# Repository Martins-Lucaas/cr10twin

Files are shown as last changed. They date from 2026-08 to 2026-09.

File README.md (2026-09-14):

<div align="center">

# cr10twin
### Digital Twin · CR10 + COVVI Hand · Biomedical Manufacturing Cell








</div>

<p align="center">
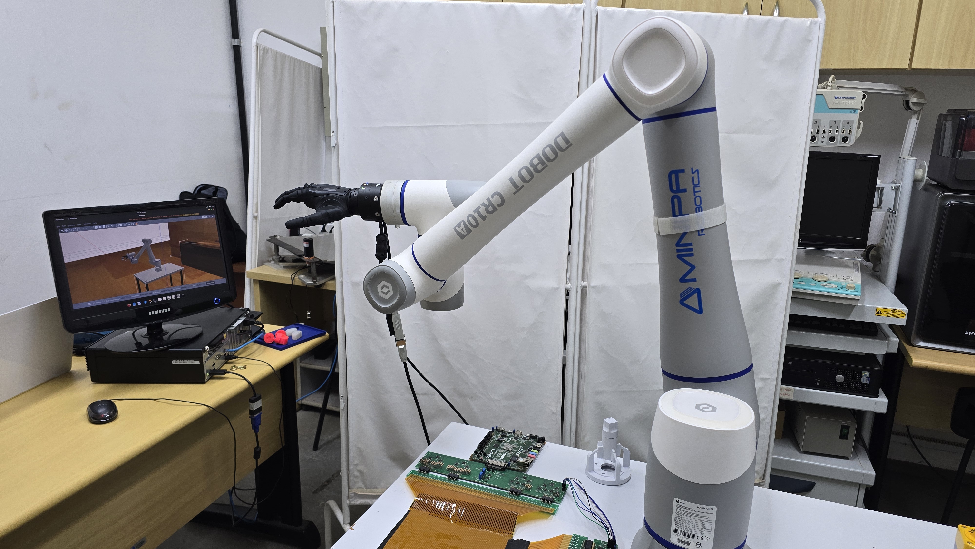
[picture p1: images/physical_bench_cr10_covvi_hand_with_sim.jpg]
Physical bench: Dobot CR10A arm with the COVVI hand mounted on the flange, and the Gazebo digital twin mirrored on the monitor at the left
  
</p>
<p align="center"><em>The physical bench — <strong>Dobot CR10A</strong> with the <strong>COVVI Hand</strong> on the flange — next to the Gazebo digital twin running the same pose.</em></p>

Digital twin of the **Dobot CR10** industrial arm coupled to the **COVVI Hand** bionic prosthetic hand, running on **ROS 2 Humble / Gazebo Classic 11**. The system identifies pharmaceutical objects on a conveyor, classifies them by the grasp type they require and drops them into the correct bins — with a direct channel to the physical COVVI hand over the ECI Ethernet protocol.

Part of an **undergraduate thesis (TCC) in Biomedical Engineering** — a virtual platform to support the training of users of multi-DOF prosthetic hands. The same hardware (CR10 + COVVI) is reused in a second **tactile palpation** cell, which reproduces the protocol of Gupta et al. 2021 with force control and Cartesian sliding.

> 🎬 **Project overview video:** [`images/tcc_video_visao_geral.mp4`](images/tcc_video_visao_geral.mp4) *(11 MB — GitHub plays it in the file viewer)*

---

## The sim ↔ real bridge

<p align="center">
  Diagram of the bidirectional Sim-to-Real and Real-to-Sim bridge between the digital twin and the CR10 + COVVI hardware
</p>
<p align="center"><em>One direction at a time, selected by mode: <strong>Sim-to-Real</strong> (the twin commands, the hardware replicates — ServoJ streaming at 33 Hz, MovJ on manual jog, COVVI hand over ECI) and <strong>Real-to-Sim</strong> (the hardware commands, the twin replicates — joint feedback at 125 Hz, which enables drag teach). Diagram labels are in Portuguese.</em></p>

<p align="center">
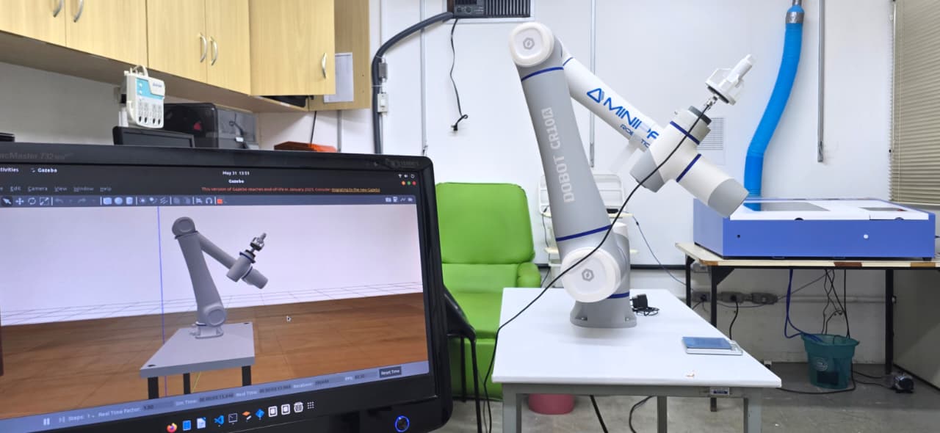
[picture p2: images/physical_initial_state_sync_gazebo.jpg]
Real CR10 next to a monitor where Gazebo shows the simulated arm in the exact same pose after startup synchronization
  
</p>
<p align="center"><em>At startup, <code>real_pose_sync</code> reads the real arm's pose and drives Gazebo to it (~3 s), so the twin is born synchronized rather than in an arbitrary URDF pose.</em></p>

---

## Hardware

| Component | Model | Specifications |
|---|---|---|
| Arm | **Dobot CR10A** | 6-DOF, 1300 mm reach, 10 kg payload, ±0.03 mm repeatability, TCP/IP V4 protocol |
| Hand | **COVVI Hand** | 5 fingers + 31 joints (6 primary + 25 mimic), ECI Ethernet interface |
| Camera | Gazebo RGB | 848×480, 70° FoV, mounted behind the conveyor |
| Load cell | 100 kg S-type cell + HX711 on a **XIAO ESP32S3** | **USB CDC only** at 115200 baud, one line per sample: `F,<seq>,<t_us>,<v_sensor>`. The WiFi/UDP path was removed on 27/07/2026 (packet loss + jitter in the HX711 front end) |
| Touch sensor | STM32 + taxel array — **4×4 or 5×5**, selected with `sensor:=4\|5` | USB-CDC at 115200 baud; Izhikevich neuromorphic model (RA/SA spikes + `I_final`). Optional UDP relay: **8081** (scalar) · **8082** (raw frame) |

<p align="center">
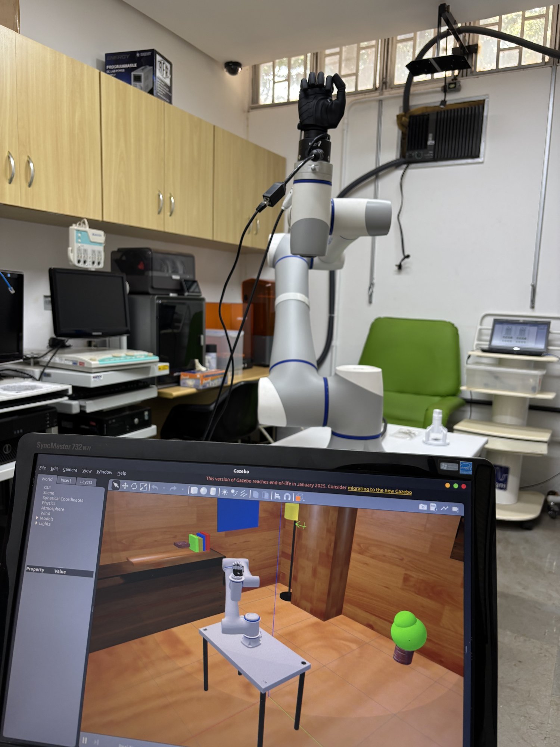
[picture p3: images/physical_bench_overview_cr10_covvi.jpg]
Full lab bench: the CR10 arm with the COVVI hand, and the Gazebo digital twin on the monitor in the foreground
  
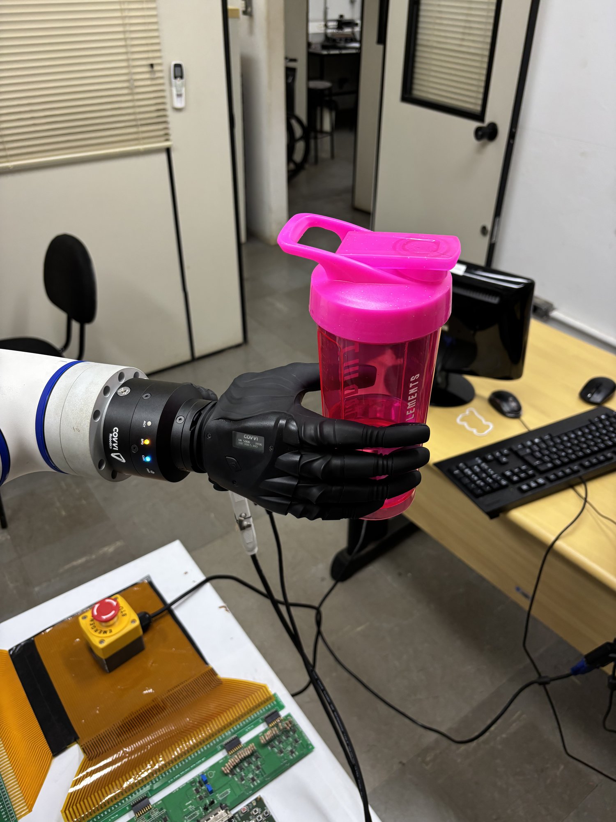
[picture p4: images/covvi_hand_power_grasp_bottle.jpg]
COVVI hand mounted on the CR10 flange holding a bottle in a power grasp
  
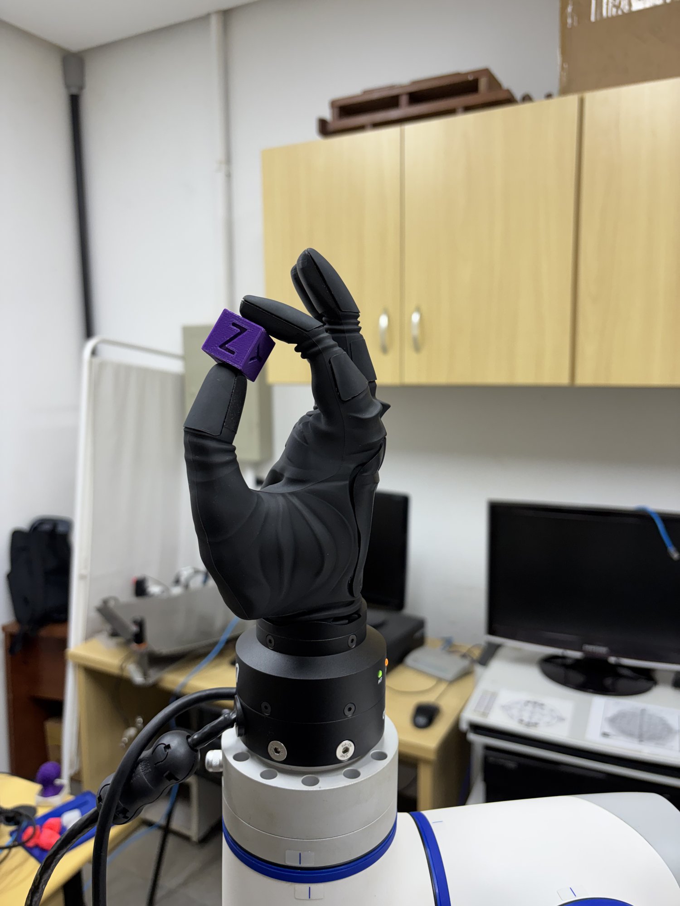
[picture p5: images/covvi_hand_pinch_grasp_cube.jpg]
COVVI hand pinching a small 3D-printed cube between thumb and index finger
  
</p>
<p align="center"><em>The real hardware in the lab: the bench with the twin on screen · a <strong>power grasp</strong> on a bottle · a <strong>pinch grasp</strong> on a 3D-printed cube.</em></p>

---

## Installation

### Option A — Docker (reproducible, one command)

```bash
git clone --recursive https://github.com/Martins-Lucaas/cr10twin.git ~/cr10twin
cd ~/cr10twin
xhost +local:docker                       # once per session, for the GUI
docker compose run --build cr10twin       # shell in a built workspace
```

The image (`Dockerfile`) pins ROS 2 Humble + every dependency and runs
`colcon build`; `docker-compose.yml` bind-mounts your checkout so you edit on the
host and re-run `colcon build` inside. Uncomment the `devices:` block for the
real load cell / touch sensor. This is the same environment CI builds on every
push.

### Option B — native

```bash
# 1. Clone WITH the eci_ros submodule (COVVI hand driver)
git clone --recursive https://github.com/Martins-Lucaas/cr10twin.git ~/cr10twin
cd ~/cr10twin
#    Already cloned without --recursive?  git submodule update --init --recursive

# 2. Dependencies
rosdep install --from-paths src --ignore-src -r -y      # apt + system deps
pip install "numpy<2" pyserial matplotlib               # numpy<2 = cv_bridge ABI
#    Optional extras (YOLO / model training / mesh regen): see "Full dependency list".

# 3. Build and source
colcon build --symlink-install
source install/setup.bash
```

`cra_description` (the CR10 URDF) is already versioned in the repository; `eci_ros`
arrives through the submodule. Nothing beyond step 1 needs to be cloned.

> **Updating the submodule later:** `git submodule update --remote src/eci_ros`
> **`symbolic link ... Is a directory` error during the build:** `rm -rf build install && colcon build --symlink-install`
> **Always run `source install/setup.bash`** in every new terminal before any `ros2 launch`/`ros2 run`.

---

## Full dependency list

> `rosdep install --from-paths src --ignore-src -r -y` now resolves the build and
> runtime dependencies — the `package.xml` files were completed (numpy, matplotlib,
> pyserial, tk, xacro, `ament_index_python`, `covvi_interfaces`, and for `hand_pack`
> also `rclpy` / `sensor_msgs` / `trajectory_msgs`). Two deliberate exceptions
> remain: **`hand_pack` is not declared** as a dependency of
> `touch_pack`/`grasp_ml_pack` (their launch files import `hand_pack.urdf_helpers`,
> but `hand_pack` already depends on both — colcon would reject the cycle), and
> the **optional** `scikit-learn` / `torch` / `ultralytics` (YOLO + model training)
> and `cadquery-ocp` (TCP mesh regen) stay `pip`-only, listed below.

### Operating system

| Dependency | Version |
|---|---|
| Ubuntu | 22.04 LTS |
| ROS 2 | Humble Hawksbill — install **`ros-humble-desktop`**, which brings `rviz2` and `rqt_joint_trajectory_controller` (both declared by `hand_pack`) |
| Gazebo | Classic 11 |
| Python | 3.10+ |

### apt packages

```bash
sudo apt update && sudo apt install -y \
  ros-humble-gazebo-ros-pkgs \
  ros-humble-ros2-control \
  ros-humble-ros2-controllers \
  ros-humble-gazebo-ros2-control \
  ros-humble-xacro \
  ros-humble-joint-state-publisher-gui \
  ros-humble-vision-msgs \
  ros-humble-cv-bridge \
  ros-humble-control-msgs \
  ros-humble-admittance-controller \
  ros-humble-kinematics-interface-kdl \
  ros-humble-force-torque-sensor-broadcaster \
  python3-tk \
  python3-pil \
  python3-pytest \
  python3-colcon-common-extensions \
  git
```

### Python

```bash
# numpy<2 is mandatory — Humble's cv_bridge is compiled against NumPy 1.x
pip install "numpy<2" opencv-python

# touch_pack — load-cell serial port and the Sensors-tab plots
pip install pyserial matplotlib

# COVVI hand driver — proprietary ECI library from COVVI Robotics
pip install covvi-eci==1.1.6

# Optional — YOLOv8 detector (only grasp_ml_pack with use_yolo:=true)
pip install ultralytics

# Optional — train the GraspQualityNet (src/grasp_ml_pack/scripts/train_grasp_model.py).
# scikit-learn drives the 'rf' backend, torch the 'nn' one. models/ ships empty,
# so anyone who wants the model has to train it.
pip install scikit-learn torch

# Optional — regenerate the palpation TCP meshes/inertias from cad/step/*.step
pip install cadquery-ocp
```

> **Optional, apt:** `python3-vtk9` enables the GPU backend of the **3D Manipulation** tab
> (the exact URDF mesh, offscreen). Without it the tab falls back to the decimated CPU
> renderer — nothing breaks.

### External dependencies — already handled by the repository

| Package | Origin | How it gets in |
|---|---|---|
| `cra_description` | extracted from [`Dobot-Arm/DOBOT_6Axis_ROS2_V4`](https://github.com/Dobot-Arm/DOBOT_6Axis_ROS2_V4) | **already versioned** under `src/cra_description` — nothing to clone |
| `covvi_interfaces` + `covvi_hand_driver` (`src/eci_ros`) | **git submodule** | cloned automatically with `git clone --recursive` (see Installation) |

> **Credits — COVVI hand driver:** `src/eci_ros` is authored by **COVVI Robotics** ([`COVVI-Robotics/eci_ros`](https://github.com/COVVI-Robotics/eci_ros)), released by them under Apache-2.0 and maintained upstream by Jordan Birdsall. It is included as a submodule pointing to a fork ([`Martins-Lucaas/eci_ros`](https://github.com/Martins-Lucaas/eci_ros)) that **fully preserves the original authorship, licence and maintainer**. The fork carries two downstream changes only: closing the ECI session on shutdown, and declaring the `rclpy` / `covvi_interfaces` runtime dependencies that the original `package.xml` omitted.

> **Note:** even in simulation-only mode, `covvi_interfaces` must be built — several nodes lazily import those types to command the real hand when it is enabled.

---

## Package guide

Each package documents how to run it in its own README.

<p align="center">
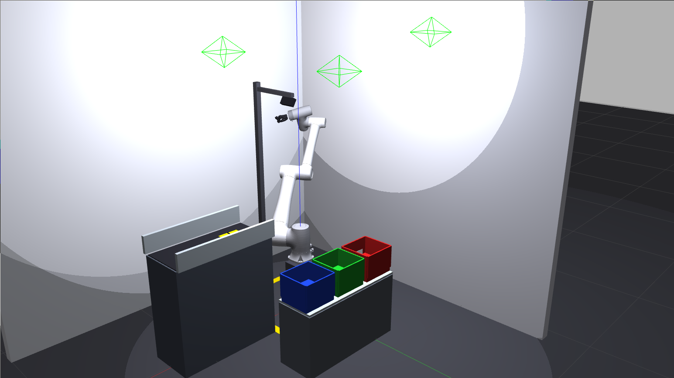
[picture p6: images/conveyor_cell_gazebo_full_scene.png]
grasp_ml_pack — the manufacturing cell in Gazebo with conveyor, arm and destination bins
  
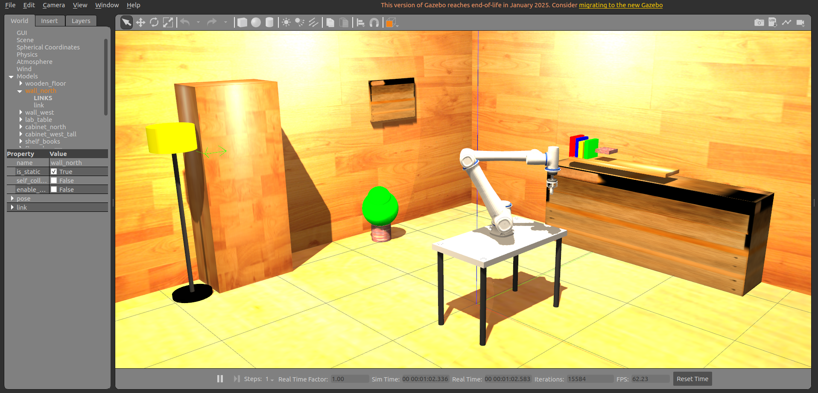
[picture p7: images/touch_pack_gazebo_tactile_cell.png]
touch_pack — the tactile palpation cell in Gazebo with the CR10 and the TouchTool tip
  
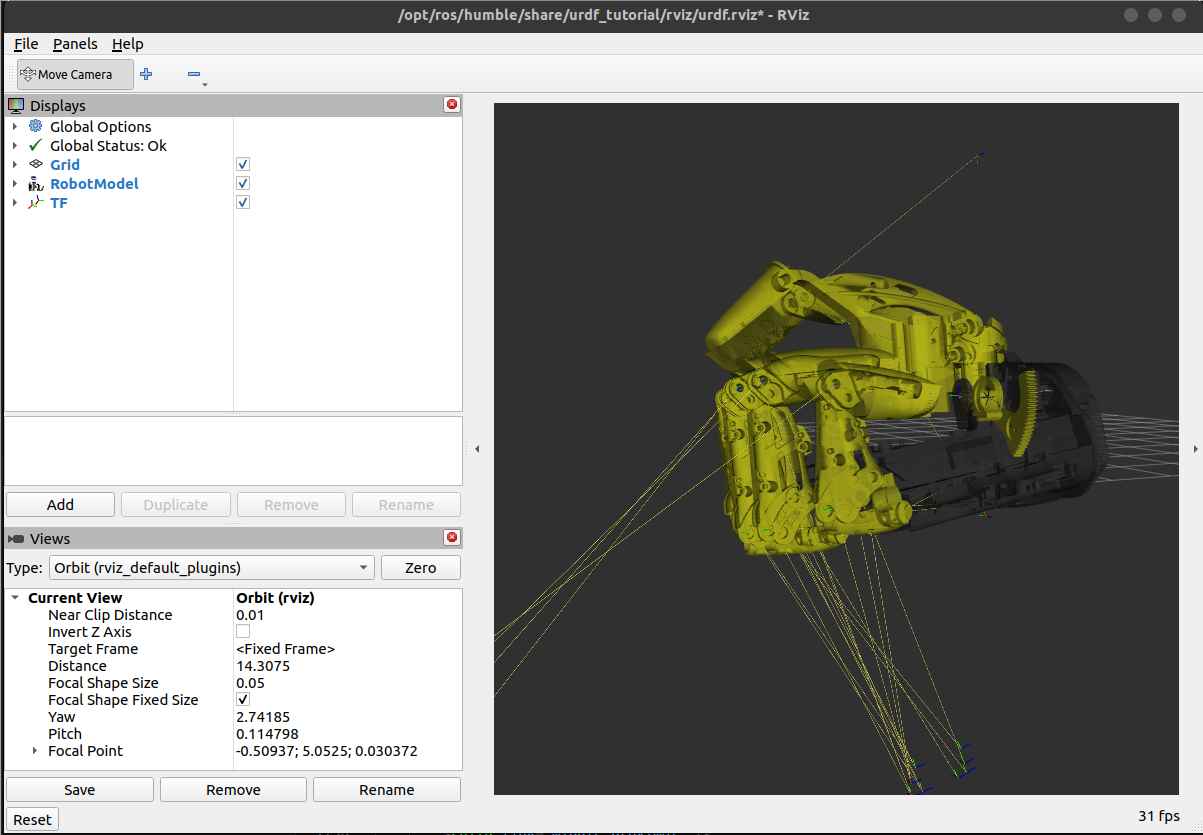
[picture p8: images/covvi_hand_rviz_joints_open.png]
hand_pack — the COVVI hand URDF in RViz with the fingers open
  
</p>
<p align="center"><em><code>grasp_ml_pack</code> — manufacturing cell · <code>touch_pack</code> — tactile palpation cell · <code>hand_pack</code> — combined CR10 + COVVI URDF.</em></p>

| Package | Main role | README |
|---|---|---|
| **`grasp_ml_pack`** | Manufacturing cell: conveyor, object detection, pick-and-place with COVVI | [→ grasp_ml_pack/README.md](src/grasp_ml_pack/README.md) |
| **`hand_pack`** | Combined CR10 + COVVI URDF, hand GUIs, launch helpers | [→ hand_pack/README.md](src/hand_pack/README.md) |
| **`touch_pack`** | Tactile palpation cell: Gupta 2021 protocol (Touch · Slide · Manual · Matrix map), GUI with 3D manipulation, logging, XIAO load cell + STM32 touch sensor (Izhikevich) | [→ touch_pack/README.md](src/touch_pack/README.md) |
| **`touch_pack_msgs`** | Message package for the palpation cell: `PalpationStart`, `PalpationStatus`, `MatrixPoint`, `SyncedTouch` | — |
| **`cra_description`** | URDF/Xacro of the Dobot CR10 arm (extracted from the official Dobot repository) | [→ cra_description/README.md](src/cra_description/README.md) |

### Palpation cell — what it can do today

| Capability | Where |
|---|---|
| **Touch** mode — press to a force setpoint and return, N times | `tactile_explorer` |
| **Slide** mode — full Gupta cycle with a lateral drag along ±X/±Y | `tactile_explorer` |
| **Manual** mode — infinite HOLD with the setpoint editable live (`/palpation/set_force`) | `tactile_explorer` |
| **Matrix map** — indents a grid of points at one setpoint; the robot discovers the plane origin itself and logs one row per indentation (`__matrix.csv`) | `tactile_explorer` |
| **Modulated force** — the HOLD setpoint follows `F(t) = mean + amp·sin(2πf·t)` (position feedforward, `Δx = ΔF/K`) | `force_mod_*` params |
| **3D Manipulation tab** — drag the TCP with the mouse, differential IK at 33 Hz, rendering the *same* URDF Gazebo got (VTK GPU / PIL CPU / skeleton fallback) | `manip3d`, `urdf_scene`, `vtk_render` |
| **Real MovJ/RelMovL execution** — palpation run by the real controller instead of ServoJ streaming (`real_movl:=true`, the default) | `real_driver` |
| **Mirroring latency measurement** — cross-correlates the simulated and physical joint series | `latency_probe` |
| **Run analysis** — aggregates `sensors/Data/*__summary.json` and classifies each run (`BOM`/`STALL`/`QUIQUE`/`MARGINAL`) | `scripts/analyze_force_runs.py` |

---

## Repository layout

```
cr10twin/
├── src/                  ROS 2 workspace (packages in the table above)
├── cad/
│   ├── step/             STEP sources of the palpation TCP — robot coupler, 100 kg cell,
│   │                     tool coupler, touch_tool and the tips A–F. The touch_pack meshes
│   │                     and inertias are regenerated from here.
│   └── SENSOR TÁTIL 5X5/ CAD of the 5×5 tactile sensor
├── sensors/
│   ├── ForceDriver/      Load-cell firmware — PlatformIO/Arduino, XIAO ESP32S3 + HX711
│   ├── Touch_sensor/     Standalone STM32 plotters (4×4 and 5×5, Linux and Windows) with the
│   │                     UDP relay to the ROS PC, plus the force-intensity classifier
│   └── Data/             Palpation runs — created at runtime by `palpation_logger`,
│                         not versioned. Layout and file formats in touch_pack/README.md
├── images/               Photos, Gazebo/GUI screenshots, diagrams and videos
├── Docs/                 Vendor manuals (Dobot, COVVI, FA7155) — local only, not versioned
├── modbus.txt            Dobot Appendix A — Modbus register map (robot as Modbus slave)
└── serial_demo.lua       RS485 example for the controller — raw serial via 127.0.0.1:60000
```

---

## Connecting the real hardware (optional)

- **COVVI hand:** from the GUI (`touch_pack`/`grasp_ml_pack`), enter the IP and click **Connect** → **ECI ON** → **PWR ON**. Internally this starts `ros2 run covvi_hand_driver server <IP>`.
- **CR10:** set `robot_ip` and use `control_mode:=mirror` (mirrors the real arm in sim) or `real_from_sim`. For *drag teach*, put the controller in **REMOTE mode** on the teach pendant.
- **Load cell (XIAO + HX711):** firmware under `sensors/ForceDriver/` (ESP32S3, PlatformIO). **The board must be on the USB cable: there is no network fallback.** `force_receiver` is the sole owner of the port and auto-detects it by USB VID; everything else consumes `/load_cell/voltage`. Calibrate in the GUI's **Load Cell** tab.
- **Touch sensor (STM32):** connects over USB (115200 baud) — the GUI reads the serial port directly in the **Sensors** tab. Pick the array with `sensor:=4` (4×4, sends `I_final`) or `sensor:=5` (5×5, no TOTAL line). Without a local serial port, run a plotter from `sensors/Touch_sensor/` and relay over UDP: port **8081** for the scalar (`touch_receiver`) and **8082** for the raw frame.

<p align="center">
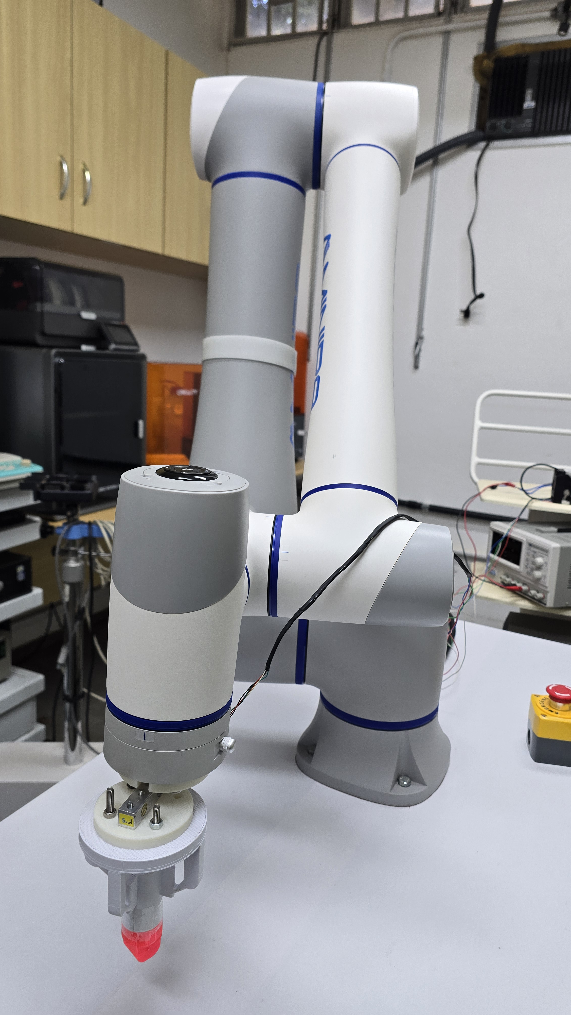
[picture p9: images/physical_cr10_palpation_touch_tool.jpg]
Real CR10 arm carrying the palpation tool: load cell between 3D-printed couplers with the red contact tip
  
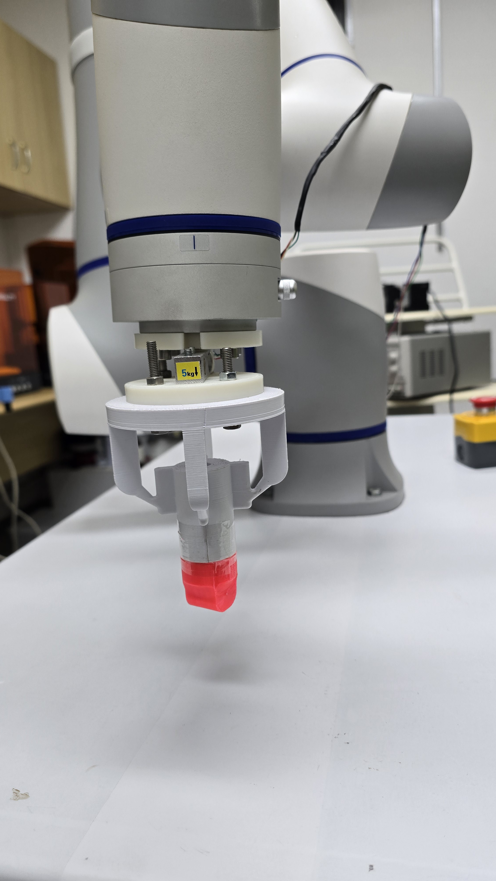
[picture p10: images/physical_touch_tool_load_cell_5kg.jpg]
Close-up of the palpation tool showing the load cell sandwiched between the printed couplers
  
</p>
<p align="center"><em>The palpation end effector on the real CR10: the <strong>100 kg load cell</strong> sits between the printed couplers, with the contact tip at the end (photos show the earlier 5 kg build in white; the current parts are all printed in blue). Swapping it for the COVVI hand is what <code>end_effector:=hand</code> vs <code>touch_tool</code> selects.</em></p>

---

## License

<div align="center">

**Apache-2.0**

Developed by **Lucas Martins** · [lucaspmartins14@gmail.com](mailto:lucaspmartins14@gmail.com)

TCC — Biomedical Engineering

</div>

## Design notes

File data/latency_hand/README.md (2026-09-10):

# Medições de latência da MÃO COVVI (Real-to-Sim)

Artefatos gerados pelo nó `touch_pack hand_latency_probe` — o análogo do
`latency_probe` (braço, em `../latency/`) para o outro elo do gêmeo digital.

Campanha de **10/09/2026**. As capturas em `pre-correcao/` foram feitas com o
bug de escala descrito no histórico abaixo: valem para LATÊNCIA, não para erro
angular. As do diretório principal são pós-correção e valem para as duas coisas.

## Como gerar

```bash
# Terminal 1 — plataforma com a mão, e a mão física conectada pela GUI
# (botão Connect → o power ON automático liga o mirror real→sim):
ros2 launch touch_pack tactile_cell.launch.py end_effector:=hand

# Terminal 2 — 20 s movimentando os dedos pela GUI (sliders ou botões de
# grip; os dois dão a mesma precisão). `auto` detecta o sentido pelo sinal:
ros2 run touch_pack hand_latency_probe --ros-args \
    -p direction:=auto -p duration_s:=20.0
```

O probe grava direto aqui (`data/latency_hand/`), que é versionado. Depois:

```bash
ros2 run touch_pack latency_report -- data/latency_hand
```

## O que cada arquivo contém

Mesmo formato do braço (ver `../latency/README.md`), com as 6 juntas
primárias da mão (`Thumb, Index, Middle, Ring, Little, Rotate`) no lugar das
6 do braço. O `_result.json` traz dois campos a mais: a taxa efetiva da
telemetria (`real_telemetry_rate_hz`) e a quantização da contagem ECI
(`real_quantization_deg`).

## Diferenças de instrumentação em relação ao braço

| | Braço | Mão |
|---|---|---|
| timeline REAL | poll readonly do CR10, 125 Hz | telemetria `DigitPosnAll`, **200 Hz** em movimento |
| quantização | — | 0,596°/contagem ECI |
| resolução do estimador | ±0,15 ms | ±0,9 ms (teste sintético, janela de 20 s) |

O stream `DigitPosnAll` é orientado a evento: cai para 10 Hz de keepalive com
a mão parada e sobe para ~200 Hz enquanto os dedos se movem. Os 10 Hz vistos
com a mão em repouso **não** limitam a medição.

## Resultado (pós-correção — 4 capturas, 24 pares)

| grandeza | mão (5 dedos) | braço (`../latency/`) |
|---|---|---|
| latência Real-to-Sim | **135,2 ± 3,1 ms** (N=20) | 71,5 ± 0,3 ms (N=17) |
| MAE (atraso compensado) | 0,977 ± 0,187° | 0,009° |
| RMSE compensado / cru | 1,63° / 5,39° (3,3×) | 0,024° / 0,558° (23×) |
| ganho sim/real | 0,936 ± 0,016 | — |

**O `Rotate` é mais rápido que os dedos, e isso agora está sustentado:**
111,6 ± 3,0 ms (N=4) contra 135,2 ± 3,1 ms. A diferença de 23,6 ms é ~7σ da
dispersão de qualquer um dos dois grupos. Nas duas primeiras capturas ele
tinha amplitude de só 4,7° e correlação 0,97, e por isso valia descartar; nas
duas últimas ele se moveu 10,4° com correlação 0,98 e o número não mudou. É
resultado, não artefato — reportar as duas latências separadas, não uma média.

Hipótese para a diferença (não verificada): o `Rotate` move o chassi do
polegar, com cadeia mimic mais curta que a dos dedos — menos juntas para o
controlador do Gazebo assentar.

## Histórico: o bug de escala (resolvido em 10/09/2026)

As 4 primeiras capturas (`pre-correcao/`) mediram ganho 0,77 e MAE de 6,3°.
Não era infidelidade do gêmeo: a junta do URDF é o **driver**, cuja faixa é
0,12–1,0 rad (6,9–57,3°), e 1,0 rad de driver dá ~163° na ponta do dedo pela
cadeia mimic. A conversão mandava grau de ponta de dedo (0–90°) direto para o
driver, então tudo acima de 57,3° ceifava no teto e o piso de 6,9° levantava a
base — exatamente o ganho de 0,77 com offset de +7°.

O `Rotate` escapava (ganho 0,95) porque é mapeado para 0–60° contra um teto de
57,3°, quase coincidente. Foi a pista que descartou as outras hipóteses.

Duas explicações foram testadas e falharam antes de chegar nesta: limite de
velocidade do URDF (o sim atinge 200+°/s contra um limite de 57°/s, ou seja
não é aplicado) e filtro passa-baixa da dinâmica do controlador (o ganho não
cai com a frequência — correlação ganho×frequência = +0,21, sinal errado).

Confirmação quantitativa: modelar o bug como `clip(pose, 0.12, 1.0)` reproduz
o ganho medido nos 20 pares com erro médio de 0,017, sem parâmetro livre.

**Correção:** `touch_pack.constants.hand_deg_to_driver_rad` passou a ser a
fronteira entre os dois espaços angulares, e `HAND_DRIVER_{LOWER,UPPER}_RAD`
viraram autoridade única — `hand_pack.urdf_helpers` (clamp do URDF) e
`touch_pack.kinematics` importam de lá em vez de manter cópias. Efeito medido:
ganho 0,77 → 0,95, offset +7° → +1,2°, MAE 6,3° → 0,86°. **A latência não
mudou** (136,58 → 136,57 ms): a correlação cruzada é invariante a escala, que
é por que as capturas antigas seguem válidas para ela.

## Critérios de qualidade de uma captura

- `peak_corr >= 0.9`;
- amplitude >= 2° no dedo dominante, em graus de DRIVER (a contagem ECI
  quantiza em 0,6° de ponta de dedo, ~0,33° de driver);
- >= 150 amostras de telemetria (o probe avisa) — na prática, 20 s de janela.

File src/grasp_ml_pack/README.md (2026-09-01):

# grasp_ml_pack

Main package of the **biomedical manufacturing cell**. It integrates computer-vision object detection, CR10 arm kinematics, COVVI hand control and orchestration of the pick-and-place cycle in Gazebo — with an optional channel to the physical COVVI hand over ECI.

<p align="center">
  Manufacturing cell in Gazebo — conveyor, CR10 with COVVI hand and destination bins
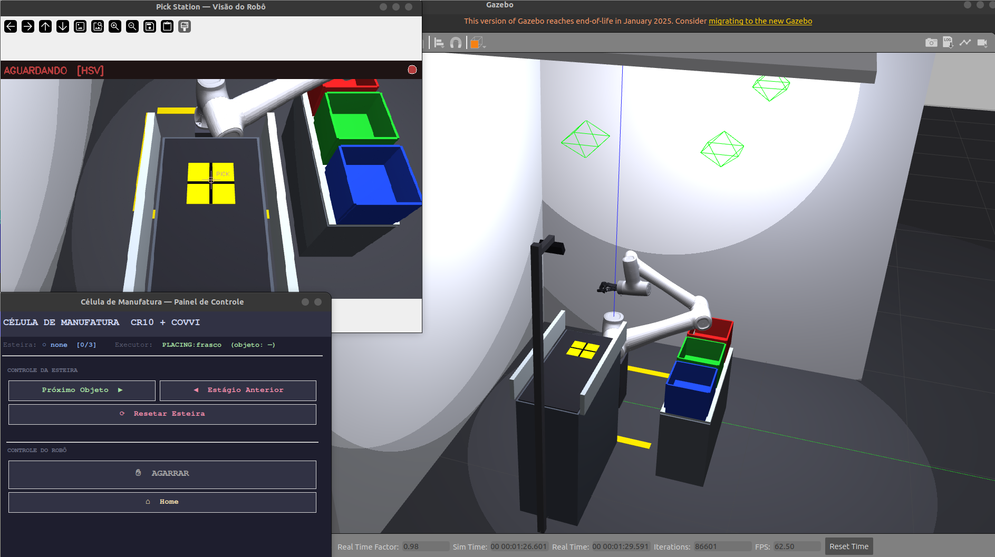
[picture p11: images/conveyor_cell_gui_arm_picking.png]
Cell GUI during a grasp — camera, detection and pick-and-place cycle control
  
</p>
<p align="center"><em>Left: the full cell in Gazebo (conveyor → pick station → bins). Right: the operation GUI during a grasp cycle.</em></p>

---

## Objects and grasps

| Object | Gazebo color | Grasp type | Destination |
|---|---|---|---|
| **Vial** (`frasco`) | Amber/orange (`H=8-26, S>120, V>80`) | Palm Grip | Box 1 — red |
| **Tube** (`tubo`) | Rich blue (`H=100-135, S>80, V>50`) | Claw Grip | Box 2 — green |
| **Ampoule** (`ampola`) | Bright green (`H=38-85, S>110, V>80`) | Fingertip Grip | Box 3 — blue |

<p align="center">
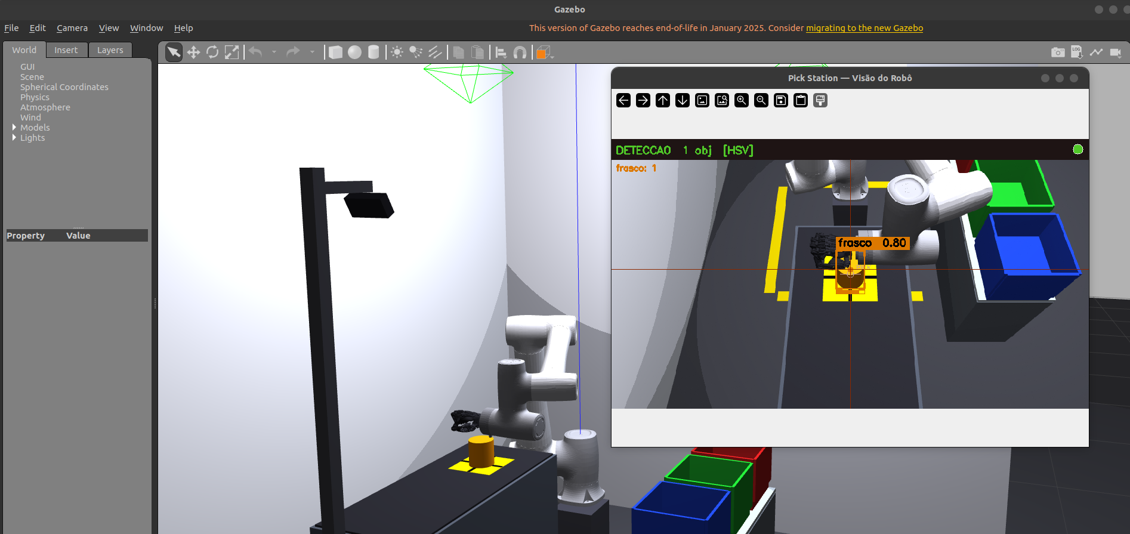
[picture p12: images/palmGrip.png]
Palm Grip — vial grasp
  
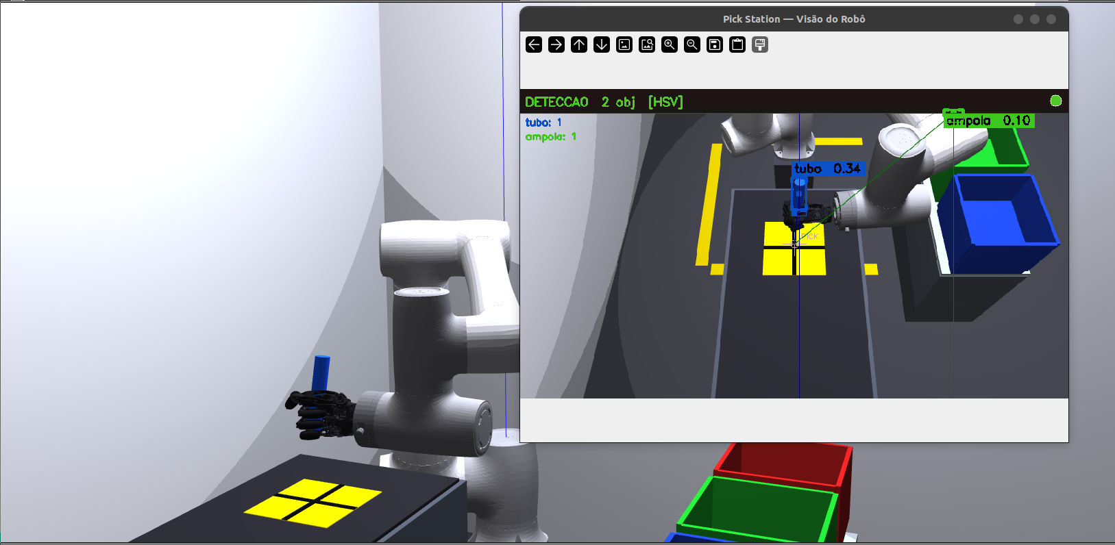
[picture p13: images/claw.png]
Claw Grip — tube grasp
  
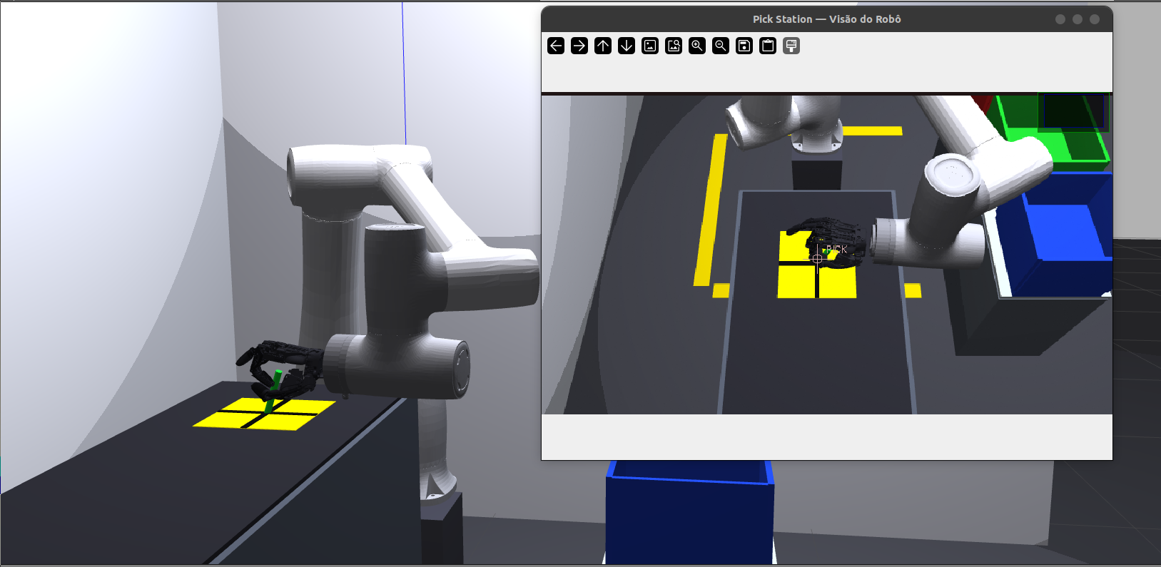
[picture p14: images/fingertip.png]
Fingertip Grip — ampoule grasp
  
</p>
<p align="center"><em>COVVI hand grasp types: <strong>Palm Grip</strong> (vial) · <strong>Claw Grip</strong> (tube) · <strong>Fingertip Grip</strong> (ampoule).</em></p>

<p align="center">
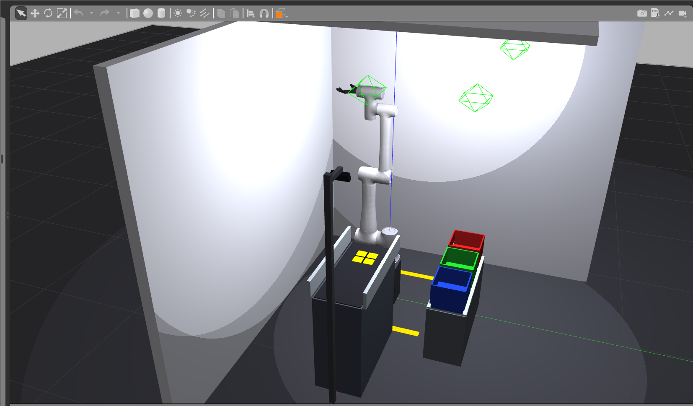
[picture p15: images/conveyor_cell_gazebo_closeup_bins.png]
Gazebo close-up of the cell: conveyor with the pick station and the three destination bins in red, green and blue
  
</p>
<p align="center"><em>The three destination bins in Gazebo — <strong>red</strong> (vial) · <strong>green</strong> (tube) · <strong>blue</strong> (ampoule) — beside the conveyor and its pick station.</em></p>

> The object identifiers used in topics, services and code are the Portuguese ones: `frasco` (vial), `tubo` (tube), `ampola` (ampoule).

---

## Architecture

```
RGB camera (Gazebo)
  │ /camera/color/image_raw
  ▼
[object_detector]  — HSV (sim) or YOLOv8 (real) → bounding box + 3D position
  │ /detected_objects (Detection2DArray)
  ▼
[grasp_executor]   — picks grip + bin → IK → runs the F1-F7 cycle
  │ /conveyor/retreat
  ▼
[conveyor_controller] — spawns/deletes objects through Gazebo services
  ▲
  │ /conveyor/advance · /cell/execute_grasp · /cell/go_home
  │
[gui_control] / [manual_control] / [pipeline]
```

<p align="center">
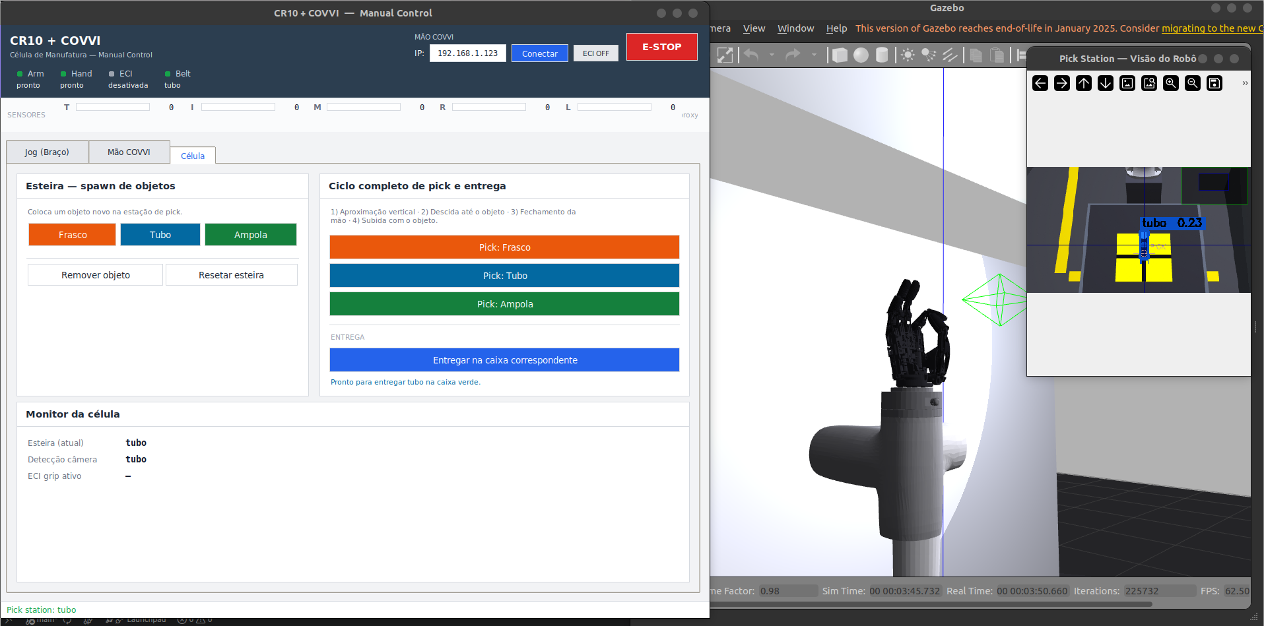
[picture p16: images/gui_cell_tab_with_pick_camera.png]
manual_control Cell tab beside Gazebo, with the Pick Station camera window showing the tube detected and labelled with its confidence score
  
</p>
<p align="center"><em>The <strong>Cell</strong> tab of <code>manual_control</code> next to Gazebo. The <em>Pick Station</em> camera window shows the live detection — here the <code>tubo</code> bounded and scored — while the cell monitor reports what the conveyor holds and what the camera sees.</em></p>

---

## Kinematics

Implemented in `grasp_ml_pack/kinematics.py` — **native URDF** convention (not DH).

### Arm forward kinematics — `forward_kinematics(q)`

Composes 6 URDF origin transforms and applies `T_HAND_ATTACH` to reach the
TCP (the convergence point of the fingertips). A **170.46 mm** translation in Z
from Link6 = prosthesis coupler **55.46 mm** + **115 mm** palm→TCP; the hand
attaches with `Rx(+90°)` (URDF), so that the finger direction coincides with
`+Link6_z` (the top-down approach axis).

| Joint | xyz (m) | rpy (rad) |
|---|---|---|
| joint1 | `(0, 0, 0.1765)` | `(0, 0, 0)` |
| joint2 | `(0, 0, 0)` | `(π/2, π/2, 0)` |
| joint3 | `(-0.607, 0, 0)` | `(0, 0, 0)` |
| joint4 | `(-0.568, 0, 0.191)` | `(0, 0, -π/2)` |
| joint5 | `(0, -0.125, 0)` | `(π/2, 0, 0)` |
| joint6 | `(0, 0.1084, 0)` | `(-π/2, 0, 0)` |

### Arm inverse kinematics — `inverse_kinematics(p_tcp, approach_vec, ...)`

1. Geometric multi-start: 14 seeds per call (q1 sweep of ±0.7 rad, two elbow branches).
2. Analytic wrist: extracts q4–q6 with both signs of q5.
3. Decoupled DLS refinement: 4 cycles (3-DOF arm DLS + analytic wrist recomputation) plus 100 iterations of 6-DOF DLS with adaptive λ.
4. Branch locking: rejects solutions with `|Δj1| > 60°` or `|Δj2| > 60°` relative to the seed.

Joint limits (URDF):
```
JOINT_MIN = [-180°, -260°, -135°, -260°, -135°, -360°]
JOINT_MAX = [+180°,   80°, +135°,   80°, +135°, +360°]
```

### Hand kinematics — `hand_fk(hand_state)`

Returns the 3D position of the fingertips, MCPs and `palm_center` in `hand_base_link`.
`grasp_center_in_hand` uses those points to align the grasp center with the
object center before running the arm IK.

**Per-finger real FK (from the URDF).** Each finger uses **its own** real
kinematic chain (origins, axes and mimic ratios) extracted from
`linear_covvi_hand_gazebo.urdf`; the tip comes from the most distal vertex of
the distal phalanx STL. This replaces the old approximate planar 2-link model,
which used a **single phalanx length (45 mm)** for every finger and placed the
`grasp_center` ~60 mm off — the cause of the grotesquely missed picks. The
chains are precomputed in `_FINGER_CHAINS` (generated offline; do not edit by
hand).

Real geometry extracted from the URDF (`hand_base_link` frame):

| Measurement | Value |
|---|---|
| Proximal phalanx (MCP→DIP) | Thumb 60.8 · Index 30.0 · Middle 34.0 · Ring 32.0 · Little 24.0 mm |
| Hand center → finger base (‖MCP‖) | ~95 mm (long fingers) · 51.9 mm (thumb) |
| Finger-to-finger (adjacent MCPs) | ~20 mm · Thumb–Index 77.5 mm |
| Link6→hand coupler | 55.46 mm + `Rx(90°)` |

Numerical validation (arm + hand FK, closed loop): the `grasp_center` lands on
the object center within **~2 mm** (was ~60 mm) for the vial and the ampoule.

### Checking the IK

```bash
# Quick FK→IK round trip (Python):
python3 -c "from grasp_ml_pack.kinematics import forward_kinematics, inverse_kinematics; \
import numpy as np; q=np.array([.3,-.3,-1.3,-1.4,.4,.1]); T=forward_kinematics(q); \
qs,ok=inverse_kinematics(T[:3,3],T[:3,2],q_seed=q); print('ok',ok)"
```

> Note: `scripts/test_kinematics.py` is out of date (it imports `DH_CR10`, which
> was removed in the refactor to the URDF convention) and fails — use the round
> trip above until the script is fixed.

---

## Grasp cycle (F1–F7)

| Phase | Action | Type |
|---|---|---|
| F1 | HOME → APPROACH (60 mm above the pick, hand open) | Joint |
| F1.5 | Per-object hand pre-shape | Hand |
| F1.55 | Tube only — step-aside −X 50 mm | Cartesian |
| F1.6 | APPROACH → PICK (descent with the hand pre-shaped) | Joint |
| F2:CAGE | Cage check: validates fingertip geometry against the object AABB | Check |
| F2 | `PerfectGrasp.close_until_contact` — incremental closing with lag detection | Hand |
| F3 | Lift with the object (+22 cm) | Joint |
| F4 | Lateral transit through via_box (`z=1.15 m`) | Cartesian |
| F5 | Descent → approach_box | Cartesian |
| F6 | Release above the bin → `/conveyor/retreat` | Cartesian |
| F7 | Return HOME | Cartesian |

<p align="center">
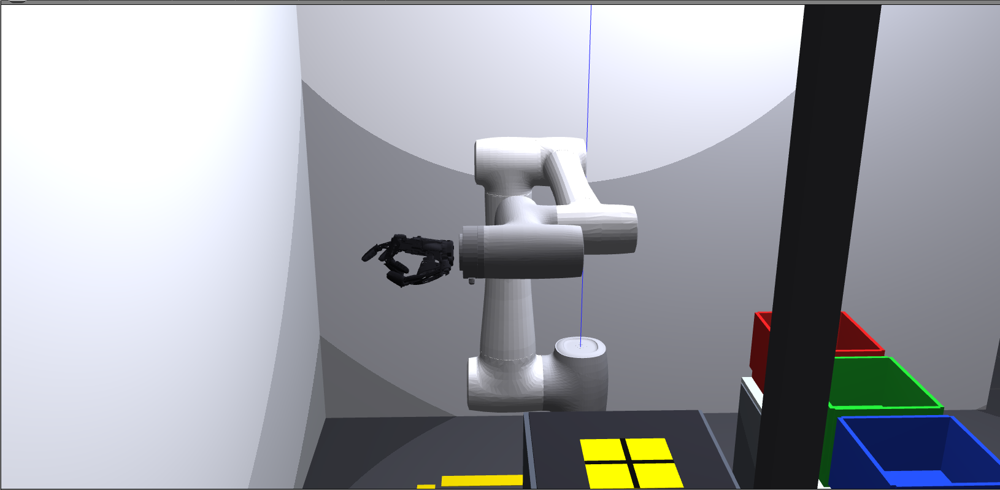
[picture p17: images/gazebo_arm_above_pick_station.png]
Gazebo: the CR10 with the COVVI hand positioned above the pick station before descending
  
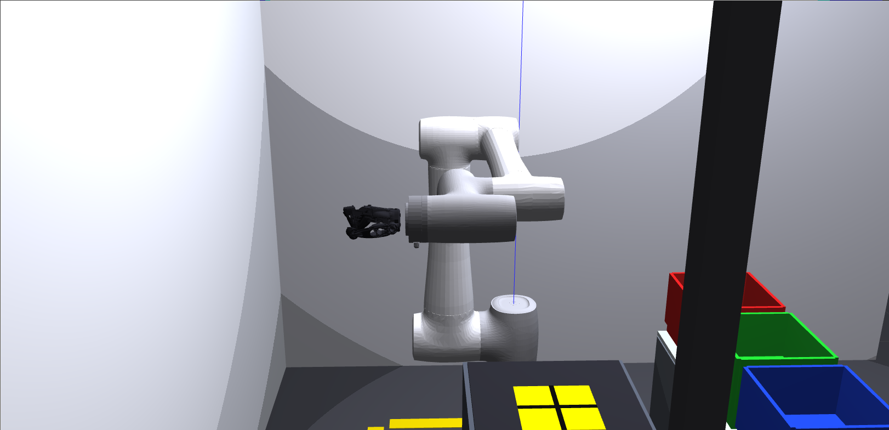
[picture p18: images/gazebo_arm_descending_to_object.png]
Gazebo: the arm descending toward the object with the hand already pre-shaped
  
</p>
<p align="center"><em><strong>F1</strong> — APPROACH, 60 mm above the pick with the hand open (left) → <strong>F1.6</strong> — descent to PICK with the hand already pre-shaped (right).</em></p>

**PerfectGrasp:** ramps at 0.06 rad / 100 ms; detects contact when `lag = commanded − actual > 0.04 rad` for 2 ticks; freezes the finger on contact. Prevents ejecting the object.

**Cage check** (`cage_check.py`): validates fingertip_z and r_tip against the object AABB. Non-fatal — it logs a warning if invalid, and PerfectGrasp still runs.

### Pick target (dynamic IK + collision)

`grasp_executor` solves the poses **at the object's real position** read from
`/gazebo/model_states` (`_solve_grasp_poses_at`); the TCP targets
(`PICK_TCP_WORLD` in `poses.py`) are computed from the hand's real
`grasp_center`. The poses cached in `poses.py` serve as a **seed** and a
**fallback** (regenerate them with `GRASP_RECOMPUTE_POSES=1` +
`recompute_and_print_poses`).

The PICK is solved **with collision checking that tolerates only `belt_surface`**
(the thin slab on top of the conveyor where the object rests — not a real
obstacle for the wrist that has to pick it up); the solid `belt_frame` structure
is still checked. Without a safe solution, the executor falls back to the
known-good cached pose instead of executing a bad IK branch.

> **Tube (lateral grasp):** with the corrected geometry, the only branch that
> reaches the tube center sinks the flange ~2 mm into `belt_frame`, so the tube
> runs on the **safe fallback** (cached pose). Adjust the clearance/height of
> the lateral approach and validate it in Gazebo before regenerating the tube
> pose. The vial and the ampoule (top-down) use the corrected dynamic IK
> normally.

<p align="center">
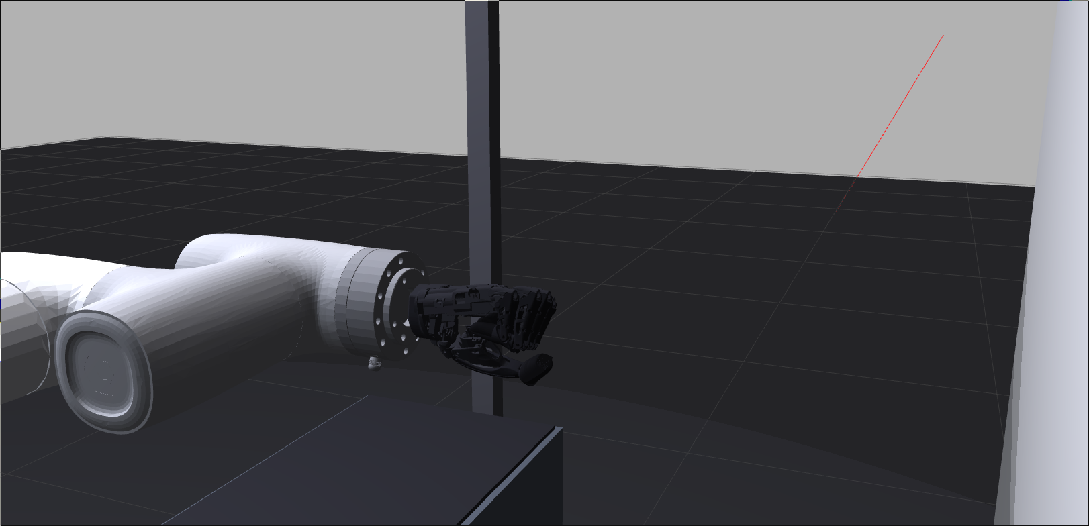
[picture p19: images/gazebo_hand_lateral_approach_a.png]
Gazebo close-up of the COVVI hand approaching the conveyor from the side
  
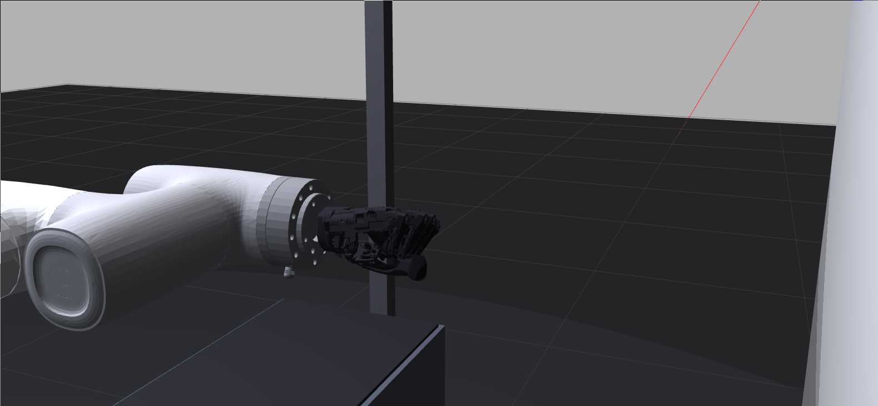
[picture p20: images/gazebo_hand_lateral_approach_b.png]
Second view of the hand in the lateral approach, near the conveyor frame
  
</p>
<p align="center"><em>The <strong>lateral approach</strong> used for the tube. It is this branch that brings the flange within ~2 mm of <code>belt_frame</code>, which is why the tube runs on the cached fallback pose.</em></p>

---

## How to run

```bash
source install/setup.bash
ros2 launch grasp_ml_pack conveyor_cell.launch.py
```

It is ready when the terminal shows:
```
[conveyor_controller] ConveyorController pronto | sequência: ['frasco', 'tubo', 'ampola']
[grasp_executor]      GraspExecutor pronto.
[object_detector]     ObjectDetector pronto — modo: HSV-simulação
```

### Launch arguments

| Argument | Default | Effect |
|---|---|---|
| `use_yolo` | `false` | Enables the YOLOv8 detector (requires `pip install ultralytics`) |
| `no_gui` | `false` | Does not start `gui_control` |
| `autonomous` | `false` | `pipeline` runs advance→detect→execute in a loop |
| `sim_only` | `true` | `false` disables the simulated part of the conveyor |

```bash
ros2 launch grasp_ml_pack conveyor_cell.launch.py no_gui:=true autonomous:=true
ros2 launch grasp_ml_pack conveyor_cell.launch.py use_yolo:=true
```

---

## Executables

```bash
# Cell nodes (started by the launch, but they run standalone if Gazebo + controllers are already up)
ros2 run grasp_ml_pack object_detector      # object detector only
ros2 run grasp_ml_pack grasp_executor       # pick-place cycle executor only
ros2 run grasp_ml_pack conveyor_controller  # conveyor controller only
ros2 run grasp_ml_pack pipeline             # status orchestrator/aggregator only

# GUIs
ros2 run grasp_ml_pack gui_control      # default GUI: conveyor + grasp
ros2 run grasp_ml_pack manual_control   # per-joint sliders + ECI grips (CRStudio-style, 3 tabs)
```

### Tuning and test scripts

Run with `python` from inside the built workspace:

```bash
python src/grasp_ml_pack/scripts/test_kinematics.py   # validates FK/IK for the 3 objects
python src/grasp_ml_pack/scripts/test_9cycles.py      # stress test: 9 consecutive cycles
python src/grasp_ml_pack/scripts/tune_descent.py      # interactive tuning of the descent phase
python src/grasp_ml_pack/scripts/tune_rotate.py       # wrist orientation tuning (joint6)
```

### `manual_control` GUI

- 6 arm sliders (joint1–joint6, in degrees, with URDF limits)
- 6 hand sliders (Thumb/Index/Middle/Ring/Little/Rotate)
- Precomputed pose buttons (Pick vial/tube/ampoule)
- Project grasp buttons (Palm/Claw/Fingertip → Gazebo)
- 14 native ECI grips (Tripod/Power/Trigger/Prec.Open/...) → Gazebo + real hand
- **Real Hand** toggle — enables sending commands to the physical hand over ECI

<p align="center">
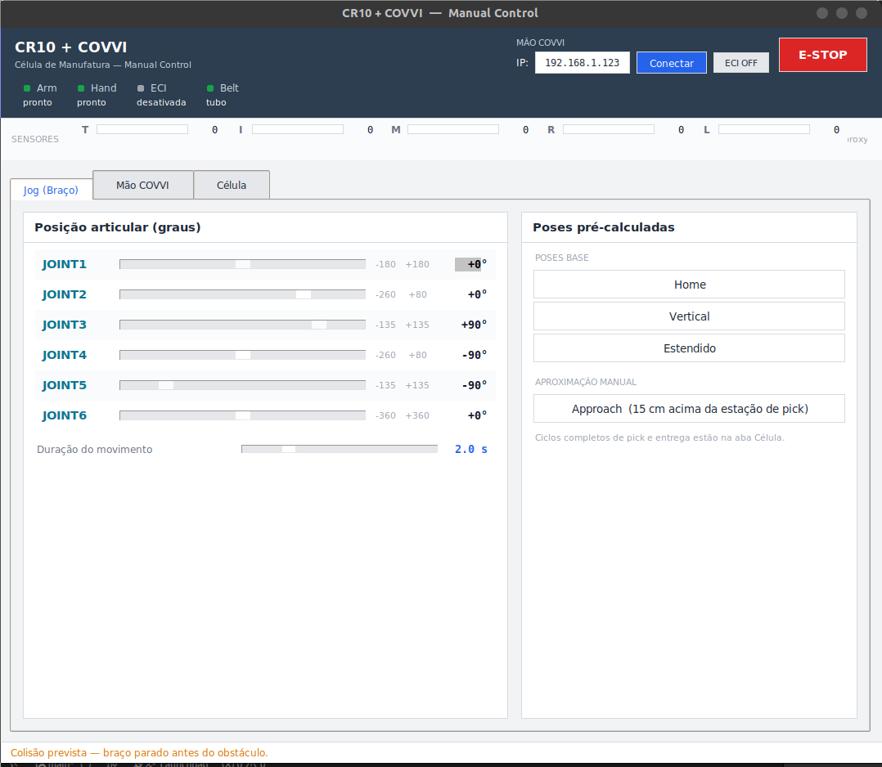
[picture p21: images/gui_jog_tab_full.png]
manual_control Arm Jog tab: six joint sliders in degrees with URDF limits, and the precomputed pose buttons
  
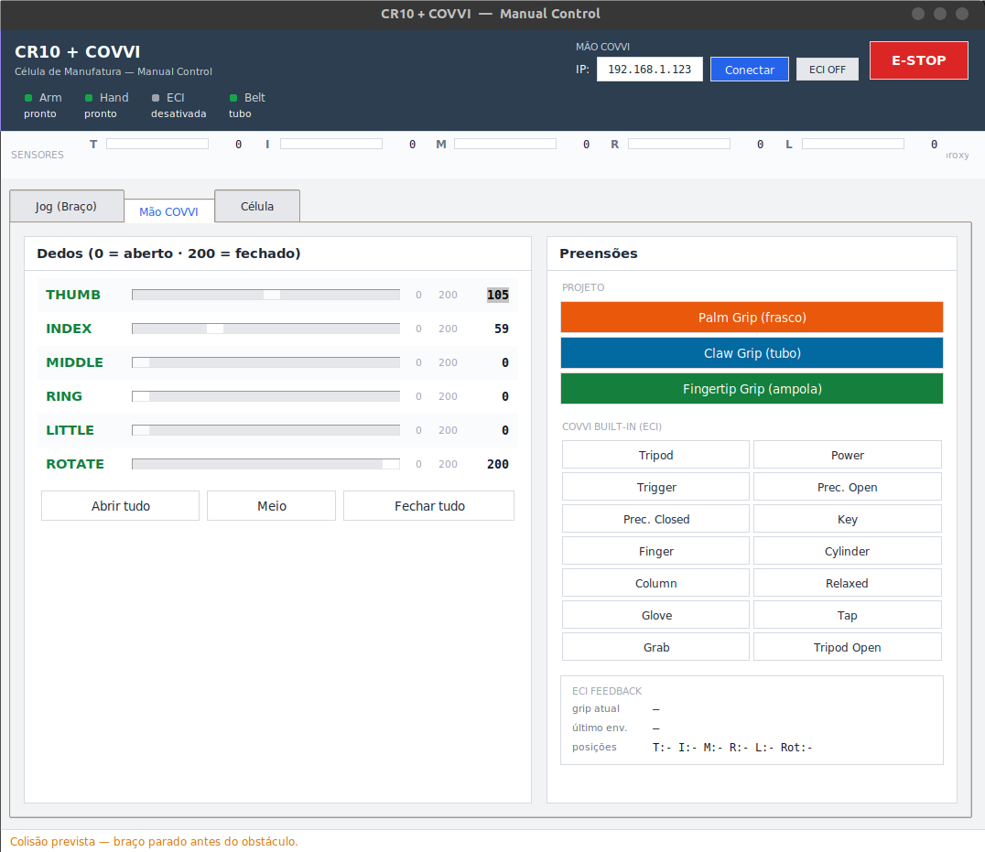
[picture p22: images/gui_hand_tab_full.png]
manual_control COVVI Hand tab: six digit sliders, the three project grasp buttons and the 14 built-in ECI grips
  
</p>
<p align="center"><em>Left: the <strong>Arm Jog</strong> tab (<code>Jog (Braço)</code>) — per-joint sliders with the URDF limits shown, plus Home/Vertical/Extended poses. Right: the <strong>COVVI Hand</strong> tab (<code>Mão COVVI</code>) — the six digits (0 = open, 200 = closed), the three project grasps and the 14 built-in ECI grips. The GUI labels are in Portuguese.</em></p>

Custom ECI prefix:
```bash
ros2 run grasp_ml_pack manual_control --ros-args -p eci_prefix:=/my/hand
```

---

## Topics and services

| Topic / Service | Type | Description |
|---|---|---|
| `/camera/color/image_raw` | `sensor_msgs/Image` | Raw camera RGB |
| `/detector/debug_image` | `sensor_msgs/Image` | Image annotated with bounding boxes |
| `/detected_objects` | `vision_msgs/Detection2DArray` | Class + 3D position |
| `/conveyor/advance` | `std_srvs/Trigger` | Spawns the next object |
| `/conveyor/retreat` | `std_srvs/Trigger` | Removes the current object |
| `/conveyor/reset` | `std_srvs/Trigger` | Restarts the sequence |
| `/conveyor/spawn_{frasco,tubo,ampola}` | `std_srvs/Trigger` | Specific spawn |
| `/cell/execute_grasp` | `std_srvs/Trigger` | Triggers the F1–F7 cycle |
| `/cell/go_home` | `std_srvs/Trigger` | Sends the arm home |
| `/cell/status` | `std_msgs/String` JSON | Executor state |
| `/cr10_group_controller/joint_trajectory` | `trajectory_msgs/JointTrajectory` | Arm commands |
| `/hand_position_controller/joint_trajectory` | `trajectory_msgs/JointTrajectory` | Simulated hand commands |
| `/covvi/hand/SetCurrentGrip` | `covvi_interfaces/srv/SetCurrentGrip` | (Real) Native grip |
| `/covvi/hand/SetDigitPosn` | `covvi_interfaces/srv/SetDigitPosn` | (Real) Absolute positions of the 6 digits |

---

## Connecting the real COVVI hand

<p align="center">
  The real COVVI hand on the CR10 flange, closed around a bottle in a power grasp
  The real COVVI hand pinching a small 3D-printed cube between thumb and index finger
</p>
<p align="center"><em>The physical hand executing a <strong>power grasp</strong> on a bottle and a <strong>pinch</strong> on a printed cube, driven over ECI from the same GUI that drives the simulation.</em></p>

### Prerequisites

- `eci_ros-main` built in the workspace (installation step 2)
- Hand connected to the network with a reachable IP (factory default: `192.168.1.123`)
- PC on the same subnet:

```bash
sudo ip addr add 192.168.1.10/24 dev <interface>
ping 192.168.1.123   # must reply
```

### ECI server

```bash
# Terminal A — keep it running the whole time
ros2 run covvi_hand_driver server 192.168.1.123 \
    --ros-args --remap __ns:=/covvi --remap __name:=hand
```

### Power on and verify

```bash
ros2 service call /covvi/hand/SetHandPowerOn covvi_interfaces/srv/SetHandPowerOn
ros2 service call /covvi/hand/GetHello covvi_interfaces/srv/GetHello
ros2 service call /covvi/hand/GetDeviceIdentity covvi_interfaces/srv/GetDeviceIdentity
```

### Telemetry

```bash
ros2 service call /covvi/hand/EnableAllRealtimeCfg covvi_interfaces/srv/EnableAllRealtimeCfg
ros2 topic echo /covvi/hand/DigitPosnAllMsg    # real positions 0–255
ros2 topic echo /covvi/hand/CurrentGripMsg     # active grip
ros2 topic echo /covvi/hand/MotorCurrentAllMsg # motor currents
ros2 topic echo /covvi/hand/DigitErrorMsg      # per-digit errors
```

### Motion commands

```bash
# Open (position 40 ≈ ECI minimum)
ros2 service call /covvi/hand/SetDigitPosn covvi_interfaces/srv/SetDigitPosn \
"{speed: {value: 100}, thumb: 40, index: 40, middle: 40, ring: 40, little: 40, rotate: 40}"

# Close (position 200 ≈ ECI maximum)
ros2 service call /covvi/hand/SetDigitPosn covvi_interfaces/srv/SetDigitPosn \
"{speed: {value: 50}, thumb: 200, index: 200, middle: 200, ring: 200, little: 200, rotate: 200}"

# Native grips: 1=Tripod 2=Power 3=Trigger 4=Prec.Open 5=Prec.Closed
#               6=Key 7=Finger 8=Cylinder 9=Column 10=Relaxed 11=Glove 12=Tap 13=Grab 14=Tripod Open
ros2 service call /covvi/hand/SetCurrentGrip covvi_interfaces/srv/SetCurrentGrip "{grip_id: {value: 2}}"
```

### Shutting down safely

```bash
ros2 service call /covvi/hand/SetCurrentGrip covvi_interfaces/srv/SetCurrentGrip "{grip_id: {value: 10}}"
ros2 service call /covvi/hand/ResetRealtimeCfg covvi_interfaces/srv/ResetRealtimeCfg
ros2 service call /covvi/hand/SetHandPowerOff covvi_interfaces/srv/SetHandPowerOff
```

> **Warning:** always go through `SetHandPowerOff` before cutting the power supply — this avoids a firmware protection state.

### Using Real Hand from the GUI

1. Start the cell: `ros2 launch grasp_ml_pack conveyor_cell.launch.py no_gui:=true`
2. Open: `ros2 run grasp_ml_pack manual_control`
3. Click **Real Hand: OFF** to enable mirroring
4. Sliders → `SetDigitPosn` with a 150 ms debounce; ECI grips → `SetCurrentGrip`

---

## Common problems

| Symptom | Cause | Action |
|---|---|---|
| `ping 192.168.1.123` does not reply | The PC's IP is outside the subnet | `sudo ip addr add 192.168.1.10/24 dev <iface>` |
| ECI server stuck at `Connecting...` | Hand powered off or another process is connected | `pkill -f covvi_hand_driver` and power-cycle the hand |
| `Real Hand: ON` but grips do not arrive | The server is not on `/covvi/hand` | `ros2 service list \| grep covvi`; check `eci_prefix` |
| `ModuleNotFoundError: covvi_interfaces` | `eci_ros-main` not built | `colcon build --packages-select covvi_interfaces && source install/setup.bash` |
| Gazebo freezes when a trajectory is sent | Controller not active | `ros2 control list_controllers` — check for `active` |
| Hand shakes when it receives a grip | Motor unpowered | `SetHandPowerOn` before the first command |

---

## Useful commands

```bash
# Rebuild only this package
colcon build --packages-select grasp_ml_pack --symlink-install && source install/setup.bash

# View the camera with bounding boxes
ros2 run rqt_image_view rqt_image_view /detector/debug_image

# Controls from the terminal
ros2 service call /conveyor/advance std_srvs/srv/Trigger {}
ros2 service call /cell/execute_grasp std_srvs/srv/Trigger {}
ros2 service call /cell/go_home std_srvs/srv/Trigger {}

# Controller states
ros2 control list_controllers

# Kill a frozen Gazebo
pkill -f gzserver; pkill -f gzclient
```

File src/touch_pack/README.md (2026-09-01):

# touch_pack

**Tactile palpation** platform built on the CR10 arm and the printed palpation TCP (load cell + tip carrying the 5×5 tactile sensor) — or the Index finger of the COVVI hand. It reproduces the protocol of **Gupta et al. 2021** (approach to a target force, controlled force hold, Cartesian slide and retraction) either in **simulation (SIM_ONLY)** or **mirroring the real robot (MIRROR)**.

It also includes a **neuromorphic touch sensor (STM32, 4×4 array + Izhikevich model)**, **synchronized force + touch recording**, and two **operating modes**: **Touch** (presses with controlled force and returns) and **Slide** (full cycle with a lateral drag).

<p align="center">
  Tactile palpation cell in Gazebo — CR10 with the TouchTool tip above the palpation table
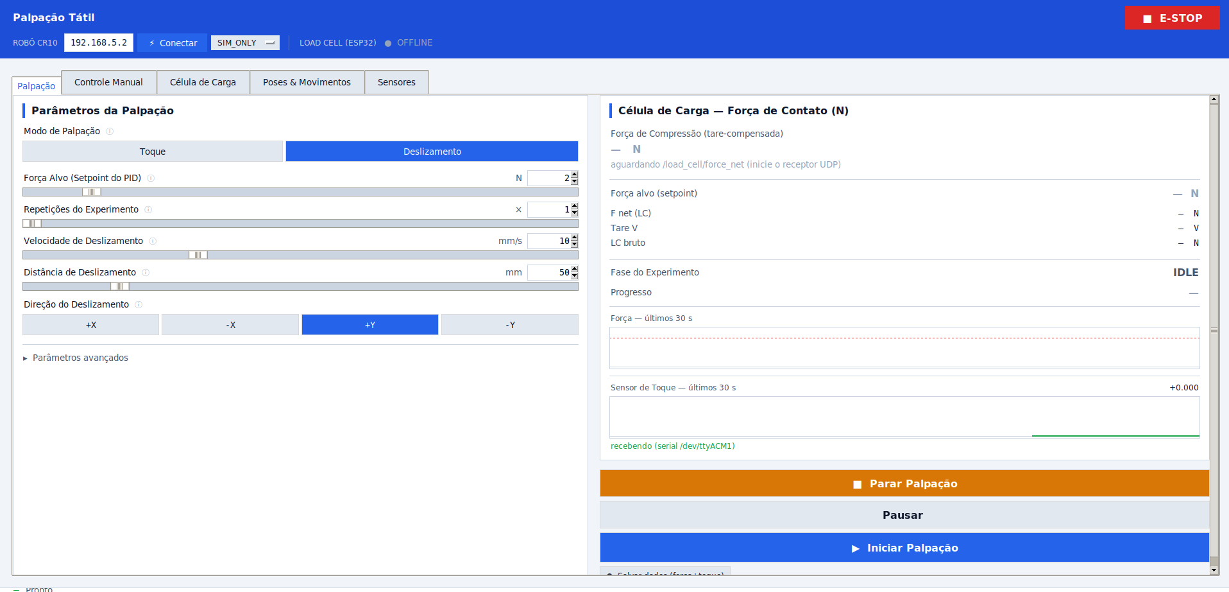
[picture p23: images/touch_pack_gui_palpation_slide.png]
Palpation GUI — Palpation tab in Slide mode with the live load-cell panel
  
</p>
<p align="center"><em>Left: the palpation scene in Gazebo Classic. Right: the <code>palpation_gui</code> — <strong>Palpation</strong> tab (Slide mode) with live readings from the load cell and the touch sensor.</em></p>

<p align="center">
  The real CR10 arm carrying the palpation tool, with the load cell and the red contact tip at the end
  Close-up of the palpation end effector: the load cell bolted between two 3D-printed couplers, contact tip in red
</p>
<p align="center"><em>The real end effector: the <strong>100 kg load cell</strong> is bolted between the lower and upper printed couplers, with the TouchTool tip at the end — the physical counterpart of the <code>touch_tool</code> URDF chain (photos show the earlier 5 kg build in white; the current parts are all printed in blue). Any cell swap requires recalibrating in the GUI's <strong>Calibration</strong> tab.</em></p>

> The GUI is written in Portuguese. Where this README refers to on-screen labels, the original text is given in parentheses.

---

## Palpation modes

The GUI splits palpation into two modes (selector in the **Palpation** (`Palpação`) tab):

| Mode | Cycle executed | Purpose |
|---|---|---|
| **Touch** (`Toque`) | `HOME → DESCENDING → HOLD → RETRACT` (repeated **N touches**) | Press against the table with controlled force and return home — no sliding. The number of touches is selectable. |
| **Slide** (`Deslizamento`) | `HOME → DESCENDING → HOLD → SLIDING → RETRACT` | The full Gupta protocol cycle, with a lateral drag along ±X/±Y. |

Both modes repeat the cycle `repeats` times automatically (between repetitions the arm retracts and returns home).

### Modulated force (Touch mode)

In **Touch** mode the HOLD setpoint can follow a trigonometric profile instead of a constant force:
`F(t) = mean + amp·sin(2πf·t)`, with `mean`/`amp` derived from the requested range.
The wave runs as a position feedforward (`Δx = ΔF/K`, `K` measured during the descent) — the load
cell is read every tick for safety, not to close the loop on the wave.

No GUI control yet; set it on the running node (search the code for `GUI HOOK force-mod` for the
three places that expose it in the GUI):

```bash
ros2 param set /tactile_explorer force_mod_shape SINE   # OFF | SINE | COSINE
ros2 param set /tactile_explorer force_mod_min_n 2.0
ros2 param set /tactile_explorer force_mod_max_n 3.0
ros2 param set /tactile_explorer force_mod_hz 10.0
ros2 param set /tactile_explorer force_mod_cycles 20    # duration = cycles / hz
```

The instantaneous setpoint is published in `PalpationStatus.target_force_n` and the logger copies it
into the `setpoint_n` column of the samples CSV, next to the measured `force_net_n`. What that column
carries is the **delivered** wave, not the commanded one: it is reconstructed from the penetration
measured by FK (×K), because in MovL mode the command is accepted before it executes and the
commanded wave runs ahead of the executed one. That is what keeps the two columns aligned in time, so
the frequency you read from the CSV is the frequency actually delivered.

The status timer runs at 10 Hz, so `setpoint_n` is a staircase with 100 ms steps — enough to measure
the frequency of a wave up to ~4 Hz, but coarser than the 33 Hz control loop that generates it.

**Rate limit:** the control loop runs at 33 Hz (`_CTRL_DT = 30 ms`), so a faithful wave needs
`f ≤ ~4 Hz` (8 points per cycle). At 10 Hz there are ~3 points per cycle: the profile still runs and
is logged, but the commanded shape is coarse and the achieved amplitude falls short of the request.
The log warns with the numbers whenever that is the case.

---

## Protocol / FSM

```
IDLE → HOME → DESCENDING → HOLD → [SLIDING] → RETRACT → HOME → IDLE
```

| Phase | Description |
|---|---|
| **HOME** | Batch joint-space trajectory (JTC S-curve) at ≤ 0.3 rad/s to the initial pose. Checks that the TCP points downward. |
| **DESCENDING** | Jacobian streaming along the approach axis (TCP −Z) with a fast→slow profile. **Force controlled:** it ends when the compression reaches the *setpoint* (`force_n`). `depth_mm` is the **maximum safety** travel. |
| **HOLD** | A quasi-static micro-step regulator brings the compression to the setpoint and **waits for it to settle**: `\|Fz − target\| ≤ tol` for `hold_stable_s` continuous seconds (capped by `hold_timeout_s`). |
| **SLIDING** | (Slide mode only) Lateral Jacobian streaming along ±X/±Y at constant velocity with orientation/depth locking; on the normal axis the force is **not regulated** — only monitored for safety. |
| **RETRACT** | Cartesian retreat along +Z (opposite the approach) by `retract_mm`. |

Control runs through **direct streaming** at 33 Hz — no action server, no trajectory queue. Each setpoint is computed and published individually, which keeps latency minimal and makes `stop`/`pause` respond immediately.

**The setpoint is approached from below.** Every pushing micro-step is capped so that, projected through the *upper bound* of the local stiffness (`k_upper`), it cannot take the force past the **target** — not past the upper edge of the band. Until 27/08/2026 the cap aimed at `target + tol`, which made stopping a whole tolerance above the setpoint the *correct* behaviour of the law: against a 0.5 N target with the 4σ band that is +18 % of force into the sample, within spec and still wrong. The asymmetry is deliberate — crossing upward puts force into a sample that may be biological, staying below costs one tick — and it is cheap: measured on the synthetic F(x) curves of `test_no_overshoot.py`, the descent peak moved from "inside the band" to **below the setpoint** in every case at a cost of zero to one tick. **The first impact aims at the contact threshold**, not at the setpoint. The touch transient is `v · T_halt · K`, and `crawl_v_ms` sizes the crawl speed so that peak lands on `CONTACT_ON_N` (0.1 N) — the first contact *detects*, and the quasi-static regulator is what climbs from there to the setpoint. Until 27/08/2026 the budget was `target + tol`, so the impact had licence to deliver the whole setpoint on its own, before any loop could react: against a 5 N run that is a 5 N blow to the sample. The peak no longer depends on the setpoint — 0.2 N and 5 N touch with the same force. **This costs descent time**, because `v` is linear in the budget: against the rigid reference tip a 1.6 N run crawled at the 200 µm/s ceiling and now crawls at ~12 µm/s, and without a learned contact the *whole* descent runs at that speed (4.5 mm of free travel goes from 22 s to 378 s). On soft contacts nothing changes — both budgets clip at the ceiling. The lever is `T_halt`: the 0.3 s in the formula is borrowed from the braking constant and **was never measured**; `v` is linear in `1/T_halt`, so at the ~85 ms measured elsewhere in the chain the crawl returns to ~42 µm/s. `latency_probe.py` is the instrument.

**Force safety:** by convention compression is **positive** and traction is negative. A measurement is **aborted** if the compression exceeds **15 N** (`FORCE_ABORT_LIMIT_N`); the force setpoint is saturated at **10 N**. If the load-cell reading goes stale (> 0.5 s), the force phases abort (`stale`).

---

## Nodes

| Executable | Role |
|---|---|
| `tactile_explorer` | Palpation FSM: subscribes to `/palpation/start`, runs the cycle (Touch/Slide mode), publishes `/palpation/status` |
| `palpation_gui` | Tkinter GUI: parameters, modes, manual control, load-cell calibration, poses/motions, touch-sensor dashboard |
| `palpation_logger` | Writes one CSV + JSON per run into `sensors/Data/` |
| `palpation_report` | Generates a per-cycle statistical report from the run CSVs |
| `force_receiver` | **Default.** Reads the **axial 100 kg cell** on the XIAO ESP32C6 over **USB serial** (sole owner of the port) → `/load_cell/voltage`, `/load_cell/force`, `/load_cell/force_net`, `/load_cell/calibrated`; relays `/load_cell/rezero` as `'Z'` |
| `ft_receiver` | Reads the **FA7155 6-axis cell** over RS485/USB (sole owner of the port) → `/ft_sensor/wrench` (all six channels) plus the same `/load_cell/*` contract the modulation loop consumes. Alternative to `force_receiver`; **never run both** |
| `touch_receiver` | Receives UDP from the touch-sensor plotter (port **8081**) → `/touch_sensor/value` |
| `force_sync` | Pairs force × touch by arrival → `/touch_sync/data` (`SyncedTouch`), one message per load-cell sample |
| `mirror_node` | Mirrors sim → real CR10 **without the GUI** (covers `no_gui:=true` in MIRROR) |
| *(module)* `manip3d` | Viewport 3D + differential IK of the **3D Manipulation** tab — no ROS, no node |
| *(module)* `urdf_scene` | Loads the cell's URDF + meshes into the triangle scene that viewport renders |
| *(module)* `vtk_render` | Optional GPU backend — renders the URDF mesh at full resolution, offscreen |
| `real_pose_sync` | Moves the simulated arm to the real robot's pose at startup (single use in the launch) |

---

## How to run

```bash
source install/setup.bash

# Full cell (Gazebo + CR10 + GUI + logger + force_rx + touch_rx)
ros2 launch touch_pack tactile_cell.launch.py

# Tactile tip + load cell (unlocks the Palpation tab) and mirroring of the real robot
ros2 launch touch_pack tactile_cell.launch.py \
    end_effector:=touch_tool \
    control_mode:=mirror \
    robot_ip:=192.168.5.2

# Headless (no Tkinter GUI) — mirror_node takes over the mirroring
ros2 launch touch_pack tactile_cell.launch.py control_mode:=mirror no_gui:=true
```

<p align="center">
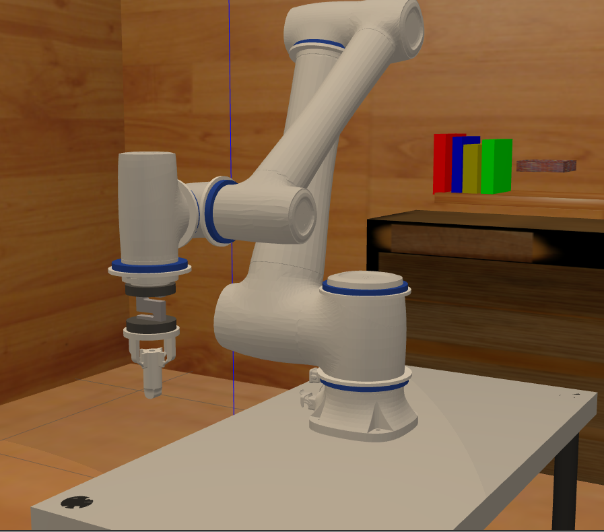
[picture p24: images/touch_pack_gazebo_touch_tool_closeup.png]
Gazebo close-up of the CR10 carrying the touch tool above the palpation table in the research_lab world
  
</p>
<p align="center"><em><code>end_effector:=touch_tool</code> in <code>worlds/research_lab.world</code> — the arm carries the contact tip instead of the COVVI hand, which is what unlocks the Palpation tab.</em></p>

### Launch arguments

| Argument | Default | Values |
|---|---|---|
| `end_effector` | `hand` | `hand` (COVVI hand control) · `touch_tool` (palpation TCP: load cell + tip with the 5×5 sensor) |
| `control_mode` | `sim_only` | `sim_only` · `mirror` · `real_from_sim` |
| `robot_ip` | `192.168.5.2` | IP of the real CR10 controller |
| `no_gui` | `false` | `true` = no Tkinter (uses `mirror_node` in MIRROR) |
| `force_sensor` | `load_cell` | `load_cell` (axial 100 kg on the XIAO+HX711 — **the cell on the bench**) · `ft6` (FA7155 6-axis over RS485) |
| `lc_port` | *(empty)* | USB port of the XIAO (`/dev/ttyACM0`). Empty = auto-detect by the Espressif VID |
| `ft_port` | *(empty)* | Port of the USB↔RS485 converter (`COM5`, `/dev/ttyUSB0`). Empty = auto-detect by VID |

> The **Palpation** tab/mode is only active with `end_effector:=touch_tool` (it needs the load cell). With `hand` the GUI shows the hand controls instead.

---

## GUI (`palpation_gui`)

A notebook with 6 tabs: **Palpation** (`Palpação`) · **Manual Control** (`Controle Manual`) · **Load Cell** (`Célula de Carga`) · **Poses & Motions** (`Poses & Movimentos`) · **Sensors** (`Sensores`) · **3D Manipulation** (`Manipulação 3D`).

### Palpation tab
- **Mode selector**: Touch / Slide (shows or hides the slide parameters).
- **Target force** (force setpoint, 1–10 N, integer) · **Repetitions / Number of touches**.
- **Slide** (that mode only): velocity (mm/s), distance (mm), direction ±X/±Y.
- **Advanced** (collapsible): max descent depth, and HOLD settling (band tolerance, stable window, timeout) plus the quasi-static micro-step ceilings.
- Live **load-cell** reading + a force sparkline.
- **Start / Stop / ⏸ Pause** buttons and **Save data (force+touch)**.
- Parameters persist between sessions (including the selected mode).

### Manual Control tab
- 6 CR10 arm sliders + (in `hand` mode) 6 COVVI hand sliders.
- Open / Point / Close presets · SpeedFactor (%) · trajectory duration.
- Home button and custom-Home saving · load-cell mini panel.

<p align="center">
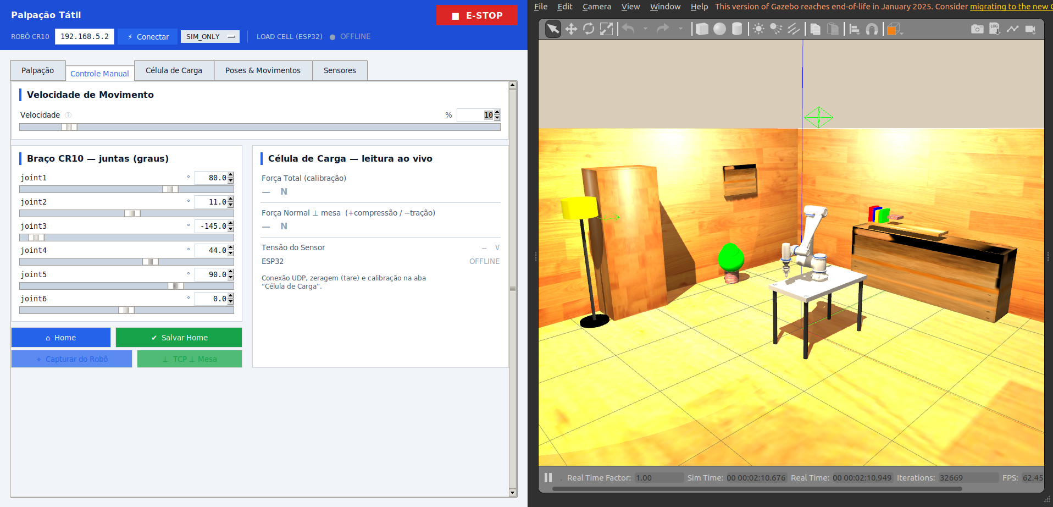
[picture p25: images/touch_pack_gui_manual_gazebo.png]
Manual Control tab side by side with Gazebo — CR10 joint sliders and load-cell reading
  
</p>
<p align="center"><em><strong>Manual Control</strong> tab next to Gazebo: jogging the 6 CR10 joints with the load cell read live (jog uses <code>MovJ</code> when in MIRROR).</em></p>

### Load Cell tab

The tab shows **the cell that is on the cable** — `force_sensor` reaches the
GUI as a parameter, the same argument that picked the receiver, so the panels
and the data can't come from different cells. Only the selected cell's sub-tabs
are built: with the S-beam on the cable, a 6-axis panel would show six
convincing zeros (nobody publishes `/ft_sensor/wrench`) and read as a dead cell.

**`force_sensor:=load_cell`** — axial 100 kg (default):
- **Reading**: net force (the number the explorer regulates and the 15 N abort
  watches) on a 0…15 N bar with a tick at the contact threshold, plus the three
  stages side by side — bridge voltage → force before tare → force after tare.
  The gap between the last two *is* the current zero, which is how you catch
  drift without unloading the tip. Board status, measured rate and whether the
  receiver has a calibration loaded. Both zeros are here, named: **Tare (host)**
  and **Re-zero the firmware ('Z')**.
- **Calibration**: a wizard that **opens with the calibration in force already
  loaded** — V₀, the points that produced it and the line itself, read from
  `sensors/load_cell_calib.json`. Capture mass `0` with the cell empty to set
  V₀, then one point per standard mass; *Clear points* starts a fresh set.
  The fit adjusts **only the slope**, holding V₀ at the measured zero, and
  writes that same file.

**`force_sensor:=ft6`** — FA7155:
- **6 Axes**: the six live channels, link health, Modbus command panel, charts,
  filter, statistics and recording. No calibration wizard — the FA7155 is
  factory-calibrated.

### Poses & Motions tab
- **Capture a pose** from the real robot (feedback port) or from Gazebo (`/joint_states`).
- **Drag Teach**: releases the real arm (`DragTeachSwitch`); Gazebo mirrors the manual motion at 33 Hz; drag is detected automatically from joint movement.
- **Motions**: sequences of N poses + a velocity → interpolated in Gazebo and paced as `MovJ` on the real arm (MIRROR).
- Persisted in `~/.config/touch_pack/poses.json`.

### Sensors tab
A dashboard for the **touch sensor (STM32, Izhikevich)** with 4 embedded matplotlib plots:
**voltage heatmap (4×4)** · **RA/SA raster** (5 s sliding window) · **I_final** · **postsynaptic neuron**, alongside the live load-cell reading.
Rendered with **blitting** (`FuncAnimation` @ 20 Hz) — only the artists that change are redrawn, and it pauses when the tab is not visible (no freezing, the raster scrolls smoothly).

<p align="center">
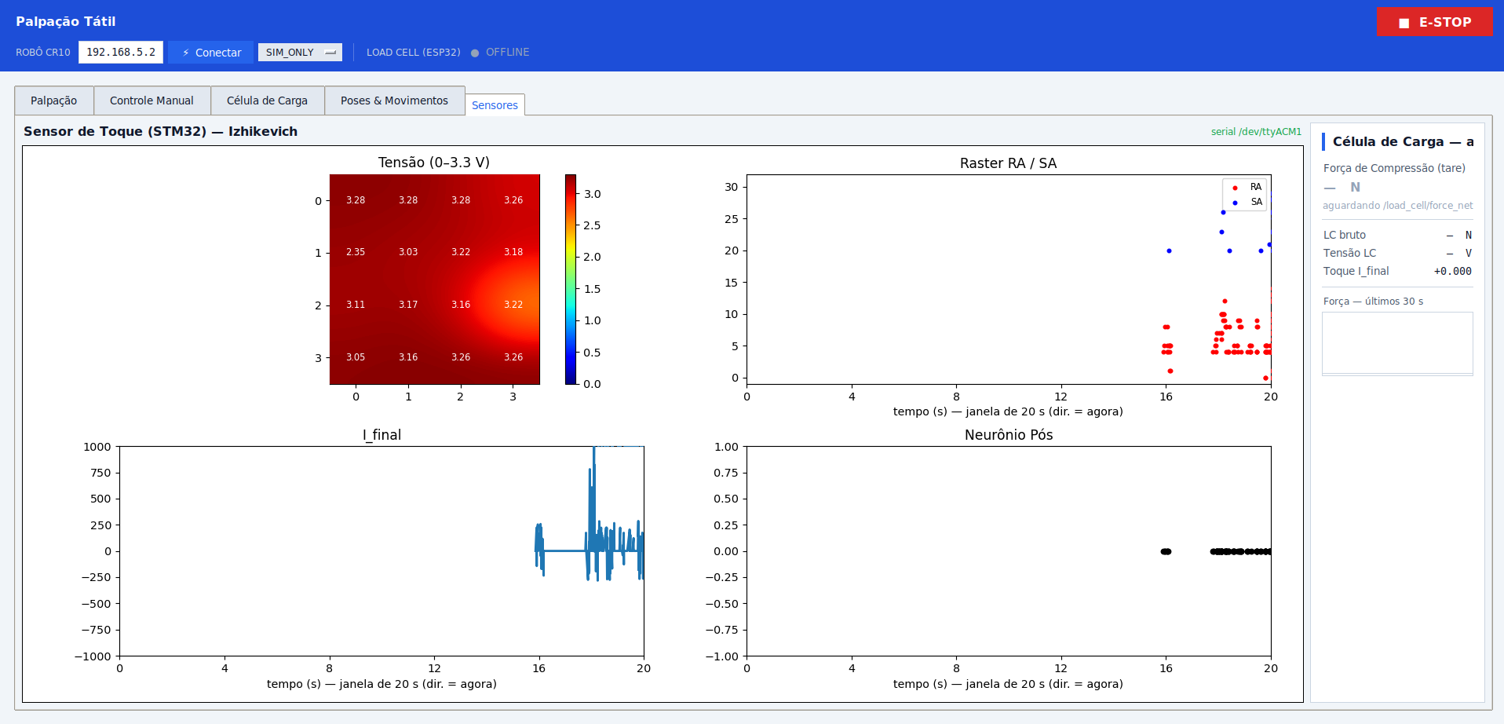
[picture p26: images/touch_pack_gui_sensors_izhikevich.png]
Sensors tab — 4×4 heatmap, RA/SA raster, I_final and postsynaptic neuron of the Izhikevich model
  
</p>
<p align="center"><em><strong>Sensors</strong> tab: 4×4 voltage heatmap, RA/SA raster, <code>I_final</code> current and the postsynaptic neuron response (Izhikevich), read from the STM32 over USB-CDC.</em></p>

### 3D Manipulation tab
Interactive 3D posing: **drag the TCP with the mouse** and the arm follows, with the inverse kinematics solved live.

<p align="center">
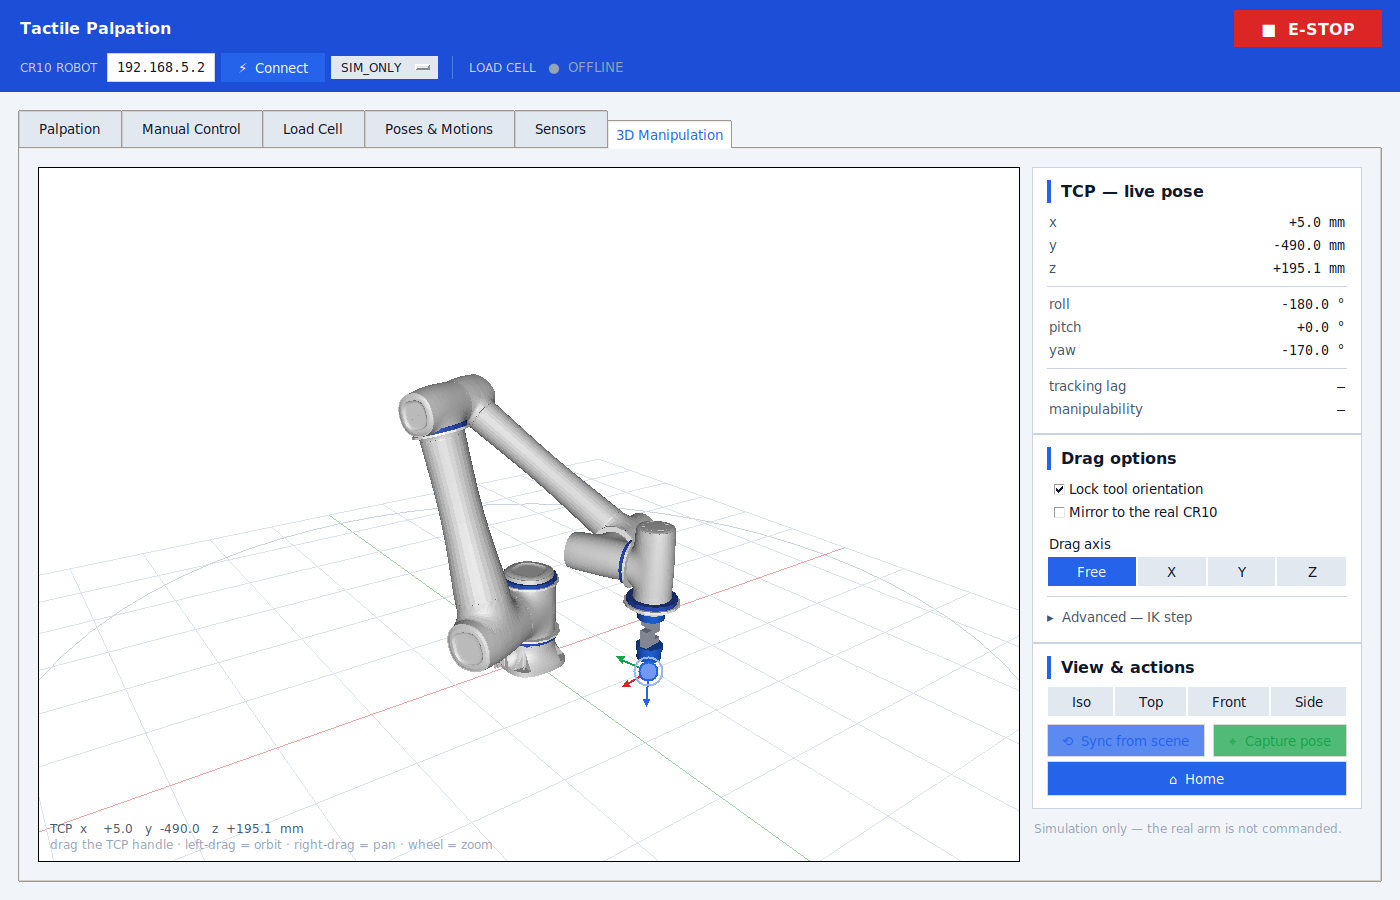
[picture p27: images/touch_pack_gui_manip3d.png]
3D Manipulation tab — the CR10 rendered from its real meshes with the palpation TCP, and the side panel with live TCP pose and drag options
  
</p>
<p align="center"><em><strong>3D Manipulation</strong> with <code>end_effector:=touch_tool</code>: the CR10 drawn from <code>cra_description</code>'s own STLs, the printed palpation stack on the flange, and the draggable handle on the TCP.</em></p>

**The model is the robot, not a stand-in.** The viewport renders the *same URDF the Gazebo spawn got* — same meshes, same joint offsets, same material colours. The launch hands its `full_urdf` file to the GUI through the `robot_description_path` parameter; run standalone, `urdf_scene.py` calls the launch's own `_build_robot_urdf()` so the two can't drift. (`/robot_description` is deliberately **not** used: `robot_state_publisher` gets the *minimal* URDF, with `<visual>` stripped by regex.)

So the CR10 arrives with its six link meshes and blue accent rings; `touch_tool` adds the printed stack (robot coupler → 100 kg S-cell → tool coupler → touch tool → tip → 5×5 sensor pad); `hand` adds the prosthesis coupler and the full COVVI hand, whose fingers **articulate live** from `/joint_states` — the URDF's `<mimic>` joints drive the 25 secondary links off the 6 primary ones, exactly as in the sim.

<p align="center">
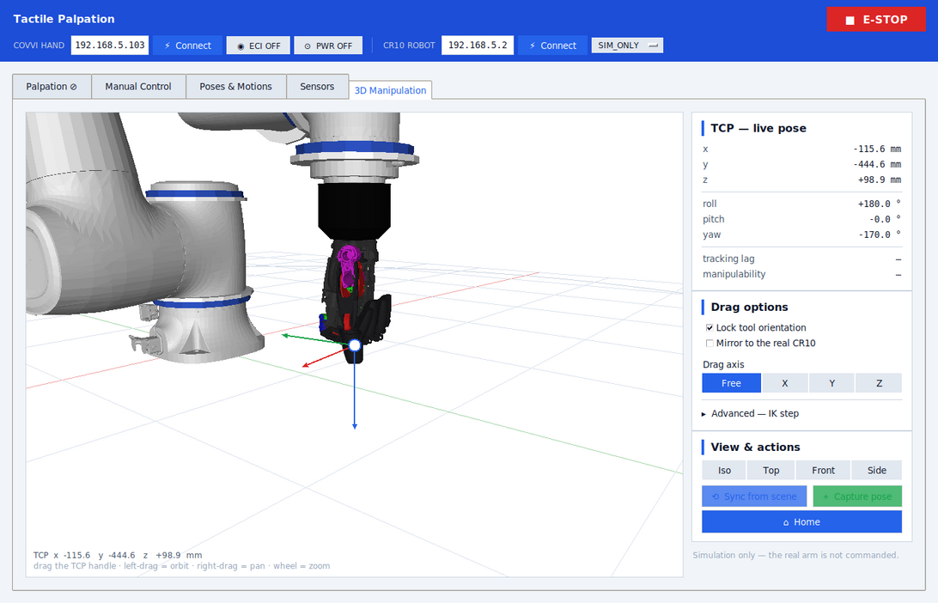
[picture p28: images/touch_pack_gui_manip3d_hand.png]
3D Manipulation tab in hand mode — CR10 with the COVVI hand rendered from its own meshes
  
</p>
<p align="center"><em>The same tab with <code>end_effector:=hand</code>, zoomed onto the end effector: the black prosthesis coupler and the COVVI hand with its fingers curled, driven live by the hand controller. The TCP handle sits at the grasp point of <code>kinematics.T_HAND_ATTACH</code> — a convention, not a URDF link, which is why it floats just past the fingertips.</em></p>

Grab the round handle on the TCP and drag it; the ground grid carries the 1375 mm reach circle.

#### Rendering backends

The mesh you see is drawn by the best backend available, and it degrades cleanly:

| Backend | Geometry | Cost per frame | When |
|---|---|---|---|
| **GPU** (`vtk_render.py`, VTK offscreen) | **the URDF mesh, exact** — no decimation at all | ~13 ms | VTK importable **and** a GL context exists |
| **CPU** (`manip3d.py`, PIL painter's algorithm) | decimated to a ~5000-triangle budget (finer still, coarser while dragging) | ~10–34 ms | no VTK / no GL |
| **Skeleton** (`tk.Canvas` lines) | FK joint origins only | <1 ms | no PIL, or meshes unreadable |

The GPU path is what makes "identical to Gazebo" literal: **62 588 triangles** for `touch_tool` and **420 042** for `hand` — every triangle of every STL — rendered offscreen and blitted into the same canvas, with the TCP handle, drag target and HUD staying as crisp Tk vector items on top. Software rasterisation *cannot* do that (the same 420 k triangles cost ~1.15 s per frame in PIL), which is why the CPU backend decimates instead.

> The vtkCamera is built to match `manip3d.Camera.project` term for term, because that projection is what places the TCP handle and resolves the click on it. `test_vtk_render.py` renders a marker at known world points and asserts the drawn pixel lands within **1.5 px** of the predicted one, across camera poses and after a resize — if the two projections ever drift, the handle would float beside the tool and the drag would grab the wrong place.

VTK is an **optional** dependency: `python3-vtk9` on Ubuntu 22.04 (already pulled in by several ROS desktop stacks). Without it nothing breaks — the tab just runs on the decimated CPU backend.

| Mouse | Action |
|---|---|
| Left drag **on the TCP handle** | Moves the TCP (runs the IK) |
| Left drag anywhere else | Orbits the camera |
| Right / middle drag | Pans |
| Wheel | Zooms |

**How the drag is solved.** The depth of the TCP is frozen at the moment of the click, so the mouse travels on the plane parallel to the screen that contains the TCP — 1 px is always the same distance in metres for the whole drag, with no scale drift. The resulting Cartesian target is chased by **differential IK**: damped least squares (DLS, λ = 0.06) over the closed-form geometric Jacobian of `kinematics.jacobian`, 6 iterations per **33 Hz** tick — the same rate as the explorer's Cartesian streaming. Each tick publishes one `JointTrajectory` point with a 100 ms horizon to `/cr10_group_controller/joint_trajectory`, and the Manual Control sliders stay in sync.

> Why not `kinematics.inverse_kinematics`: the full solver sweeps ~16 seeds × 300 iterations looking for the best *global* solution. It costs tens of ms and, worse, it can jump between elbow/wrist branches from one frame to the next — the arm would snap mid-drag. The differential step always starts from the current pose, so it is continuous by construction and runs in tens of µs.

Panel options:

| Control | Effect |
|---|---|
| **Lock tool orientation** (default **on**) | The mouse moves the *point*; the wrist works to preserve the current TCP attitude. Unchecking frees the wrist — looser, but it reaches further before hitting a joint limit. |
| **Mirror to the real CR10** (default **off**) | Off, the drag moves **only** the simulated arm. On (and in MIRROR), the pose reached is sent as `MovJ` when the drag settles — the 80 ms debounce means the hardware follows the *result* of the drag, not every frame of it. |
| **Drag axis** — Free / X / Y / Z | Free = the camera plane. X/Y/Z projects the motion onto that world axis (e.g. descend in Z without drifting sideways). |
| **Advanced** — max linear step (mm) · max joint step (°) | Ceilings per IK iteration: they limit the TCP velocity and keep the pose continuous near a singularity. |

Live readout of the TCP (x/y/z in mm, roll/pitch/yaw in degrees), the **tracking lag** (how much the IK still owes the cursor) and the **manipulability** (Yoshikawa) — the HUD flags a singular Jacobian, a joint limit or an out-of-reach target. **Capture pose** saves the pose straight into the *Poses & Motions* tab; **Sync from scene** pulls the current pose back from `/joint_states`.

Same gates as the joint jog: the drag is blocked during palpation (the explorer is streaming on the same JTC topic), during **drag teach** (the real arm's motors are released) and while a motion is running — and if a gate *closes mid-gesture* the drag is aborted rather than left spinning the IK against a blocked publisher. The 3D drag can never switch drag teach on: the auto-detector only arms on movement measured on the **real** arm with no PC command outstanding, and with mirroring off nothing is ever sent there.

**Frame budget.** The meshes are read and prepared once, in a background thread (≈1 s), while the skeleton stands in. On the GPU backend the exact mesh holds **~13 ms/frame** in both end-effector modes, so the drag runs at the full 33 Hz with nothing simplified. On the CPU backend two levels of detail are kept — the full budget when the view is still, a coarser one while you drag or orbit. Either way the IK and the JTC publish always run at 33 Hz regardless of what the picture costs: if a frame overruns, the renderer drops frames instead of slowing the arm.

### Header
- Hand and CR10 arm IPs + Connect/Disconnect · SIM_ONLY ↔ MIRROR dropdown · ECI ON/OFF · PWR ON/OFF · **CAM ON/OFF** · E-STOP.

#### Camera hand control (`CAM`)
Vision-based teleoperation of the COVVI hand. Toggling **CAM ON** (only in `hand` mode) opens the default USB camera (`camera_index`, default `0`), tracks one hand with **MediaPipe Hands** and maps per-finger flexion onto the 6 COVVI hand sliders in real time — so it drives the sim, and the real hand too when **ECI** is ON. A separate OpenCV window shows the tracked landmarks and the flexion bars; press `ESC` on it, toggle **CAM OFF**, or close the GUI to release the camera.

Optional dependency, lazily imported: `python3 -m pip install "mediapipe>=0.10,<0.11"`. If it is missing the button reports it and does nothing else. The landmark→flexion math lives in `touch_pack/hand_camera_teleop.py` (`curls_from_landmarks`, unit-tested without a camera); the tuning constants at the top of that file usually need a pass on a new camera/lighting setup.

---

## Touch sensor (STM32)

A **4×4 taxel** array read over USB-CDC (115200 baud, ACM/USB port auto-detection). The firmware emits voltages, RA/SA *spikes* (neuromorphic model) and the final current `I_final` of the postsynaptic neuron (**Izhikevich** model).

- `touch_source.py` (`TouchSensorSource`) reads the serial port directly on the GUI's PC and feeds the **Sensors** tab; it publishes `/touch_sensor/value` (throttled to 100 Hz).
- Without a local serial port, `touch_receiver` receives the reading relayed over UDP (port **8081**) and publishes the same `/touch_sensor/value` — the GUI falls back to that mode automatically.

---

## Force × touch synchronization

`force_sync` pairs the latest fresh sample of `/load_cell/force` with the latest of `/touch_sensor/value` and publishes `touch_pack_msgs/SyncedTouch` on `/touch_sync/data` at **50 Hz** (the load cell's own rate). Each pair carries `load_cell_age_ms` / `touch_age_ms` so the synchronization quality can be assessed *a posteriori*.

---

## Where the data is saved

Everything goes to **`<repo_root>/sensors/Data/`** (override with the `TOUCH_PACK_DATA_DIR` environment variable). The directory is located automatically by walking up from the package until `sensors/` is found — this works both when running from `src/` and from `install/`.

**One folder per mode, one per run** — every file of a sample lands together:

```
sensors/Data/
├── MATRIX_MAP/
│   └── 20260812_143012/     ← run_id: wall clock at Start, stamped by the GUI
│       ├── samples.csv          sensors.csv      matrix.csv
│       ├── adc.csv              spikes.csv       cuneiformes.csv
│       └── params.json          summary.json     plot.png
├── TOUCH/ · SLIDE/ · MANUAL/    same structure
├── RECORDING/                   GUI Record button pressed outside a run
└── latency/                     latency_probe captures
```

The `run_id` travels in the `PalpationStart` message so that the logger and the GUI — which write different files of the same run — agree on the folder. It is **wall-clock**, not the ROS clock: under `use_sim_time` the ROS clock restarts from zero on every launch, which used to name every run `19691231_*` and silently overwrite the previous session's data.

| File | Source | Contents |
|---|---|---|
| `samples.csv` | `palpation_logger` | `t_rel_s, t_unix, cycle, phase, setpoint_n, force_net_n, q1..q6, tcp_x/y/z, wp_index, wp_x_mm, wp_y_mm, taxel_0..taxel_24, n_RA, n_SA, cn_mm, cn_ra, cn_sa` — one row per sample |
| `matrix.csv` | `palpation_logger` | **MATRIX_MAP only** — one row per finished indentation (see below) |
| `params.json` | `palpation_logger` | parameters from `/palpation/start`, including the `run_id` (read by `palpation_report`) |
| `summary.json` · `plot.png` | `palpation_report` | post-run metrics per cycle/phase, and force×time coloured by phase |
| `sensors.csv` | the GUI, at Start (or its **Record data** button) | 1 kHz stream: net force, raw LC, LC voltage, `touch_i_final` and the taxel voltages (`v00..v44`) |
| `adc.csv` · `spikes.csv` · `cuneiformes.csv` | the GUI | raw firmware lines, same format as the standalone collection plotter |

Runs collected before this layout stay loose in the root of `sensors/Data` with the old names (`<ts>__samples.csv`); `palpation_report` and `analyze_force_runs` read both. To move them into the new layout:

```bash
python3 src/touch_pack/scripts/migrate_runs_layout.py            # shows the plan
python3 src/touch_pack/scripts/migrate_runs_layout.py --apply    # moves the files
```

- The run closes automatically on `DONE`/`ABORTED`; a watchdog closes it if samples stop arriving.
- Periodic flushing — no data is lost if the node dies.

### Associating force curves with map coordinates

In `MATRIX_MAP` every sample of `samples.csv` carries `wp_index` (1-based; `0` outside the matrix) plus `wp_x_mm`/`wp_y_mm`, the planned target of that indentation relative to the discovered origin. `matrix.csv` has one row per indentation and its `index` column joins straight onto `wp_index`:

| Column | Meaning |
|---|---|
| `index` · `total` | waypoint number / matrix size (`index = 0` is the origin-discovery touch) |
| `plan_x_mm` · `plan_y_mm` | target requested by the GUI, relative to the origin |
| `rel_x_mm` · `rel_y_mm` | where the TCP **actually** touched, relative to the origin — `rel − plan` is the positioning error |
| `depth_mm` | penetration below the origin plane |
| `setpoint_n` · `force_n` · `force_err_n` | requested setpoint, force reached at the end of HOLD, and their difference |
| `tcp_x/y/z` · `origin_x/y/z` | absolute URDF-world coordinates (m) |
| `t_start_unix` · `t_end_unix` · `t_rel_start_s` · `t_rel_end_s` | descent start and HOLD end, in absolute and run-relative time |
| `outcome` | `ok` · `no_contact` · `force` · `stale` · `timeout` · `stop` · `error` |

So filtering `samples.csv` by `wp_index == N` cuts out exactly the force curve of point `N`, whose spatial coordinate is row `N` of `matrix.csv`.

---

## Tactile mapping — `MATRIX_MAP`

Maps a plane or object by indenting a grid of points, all at the **same force setpoint** (the `Force Setpoint` field of the Palpation tab).

**Operator workflow**

1. **Jog the arm manually** until the probe sits just above the first point. `MATRIX_MAP` does *not* start from HOME — the jog pose is the starting pose.
2. In the Palpation tab pick mode **Matrix**, choose the shape (`Square`/`Rectangle`), the X/Y pitch, the number of columns/rows, the `Safe Z` and the transit velocity. The canvas previews the grid, the serpentine visiting order and the origin marker before you press Start; it also lights up the point currently being touched during the run.
3. **Start.** The first thing the robot does is descend in Z until the load cell registers contact — that TCP position becomes the origin **(0,0,0)** of the plane and is logged as `index = 0`.

**FSM**

```
IDLE
 └─ exploratory descent (DESCENDING → HOLD) ......... defines the ORIGIN
     └─ lift to Safe Z (origin_z + safe_z_mm)
         └─ for each waypoint:
              TRANSIT   XY in the air, at Safe Z
              DESCENDING → HOLD at the GUI setpoint
              lift back to Safe Z
             └─ end of matrix → RETRACT → HOME (DONE)
```

`DESCENDING` and `HOLD` are the **same** phases used by TOUCH/SLIDE — the quasi-static force regulator is not reimplemented for this mode. Only the spatial routing is new.

**Linear cartesian motion.** Transit never drags the probe over the part: rise → move in XY → descend, always with the probe out of contact. `_move_linear_world()` routes to the primitive of the current mode, neither of which invents new kinematics:

- **Streaming/Gazebo** — `_cartesian_batch_to()` converts the desired cartesian twist into Δq through the damped-least-squares TCP Jacobian, iterating FK per waypoint and publishing one `JointTrajectory`. `lock_ori` keeps the probe pointing down, `lock_z` keeps the Safe Z from drifting along the path. It is exactly the primitive SLIDING already uses, just running in free air.
- **Real arm (MovL)** — a single `RelMovLUser`, with completion measured by FK of the real feedback, not by elapsed time. Because the XY delta needs the measured world→DOBOT matrix and `MATRIX_MAP` never passes through HOME (where other modes calibrate), the frame is calibrated in free air at the start of the run.

**Safety.** The Golden Rule holds throughout: a `STOP` during transit, descent or hold aborts the matrix loop immediately, relieves the contact, rises in +Z and falls into `_abort_to_home()`. The `_FORCE_SAFE_LIMIT_N` / `_FORCE_ABORT_LIMIT_N` limits act as usual, and during in-air transit *any* force above the contact margin halts the motion at once. Waypoint lists that are empty, malformed, over the point cap or outside the ±`MATRIX_SPAN_MAX_MM` envelope get the run refused before anything moves.

---

## ROS interfaces (`touch_pack_msgs`)

### `/palpation/start` — `touch_pack_msgs/PalpationStart`
A **typed** message (it replaces the old JSON inside `std_msgs/String`):

| Field | Meaning |
|---|---|
| `mode` | `'TOUCH'` · `'SLIDE'` · `'MANUAL'` · `'MATRIX_MAP'` · empty = SLIDE |
| `force_n` | force setpoint (N, compression) — in `MATRIX_MAP` it is applied at **every** point of the grid |
| `depth_mm` | maximum descent travel — safety |
| `speed_mms` · `slide_dist_mm` · `slide_dir` | slide parameters (`+X`/`-X`/`+Y`/`-Y`) |
| `approach_speed_mms` | descent/retreat velocity |
| `repeats` | number of cycles / touches (≥ 1); ignored in `MANUAL` and `MATRIX_MAP` |
| `speed_factor_pct` | real arm SpeedFactor (%) |
| `home_deg[6]` | arm home (degrees, joint1..joint6) |
| `hold_tol_n` · `hold_stable_s` · `hold_timeout_s` | HOLD settling (0 = default) |
| `hold_dx_max_um` · `hold_df_max_n` | quasi-static micro-step ceilings (0 = default) |
| `waypoints` | `geometry_msgs/Point[]` — **MATRIX_MAP** grid, in **metres**, **relative to the origin the robot discovers**; `z` is ignored. Empty in `MATRIX_MAP` ⇒ run refused |
| `safe_z_mm` | transit height above the origin (0 = default 10 mm) |
| `transit_speed_mms` | XY in-air transit velocity (0 = default) |
| `grid_shape` | `'SQUARE'` · `'RECT'` · `'CUSTOM'` — label for the log/report |

### `/palpation/status` — `touch_pack_msgs/PalpationStatus`
`phase`, `cycle`, `cycles_total`, `target_depth_mm`, `target_force_n`, `force_net_n`, `speed_mms`, `paused`, `home_known` (current home has a learned contact ⇒ two-stage descent; the GUI mirrors it on the **Home conhecida** checkbox), plus the MATRIX_MAP stamp: `wp_index`, `wp_total`, `wp_x_mm`, `wp_y_mm`, `origin_valid`, `origin_x/y/z_m`.

### `/palpation/matrix_point` — `touch_pack_msgs/MatrixPoint`
Published by the explorer at the end of **each** indentation of `MATRIX_MAP`; the logger turns it into `__matrix.csv` (columns above).

### Other topics
| Topic | Type | Description |
|---|---|---|
| `/palpation/stop` | `std_msgs/String` | stops the experiment |
| `/palpation/pause` | `std_msgs/Bool` | pauses (holds position) / resumes |
| `/palpation/freeze` | `std_msgs/Empty` | freezes in place (no retreat) |
| `/palpation/set_force` | `std_msgs/Float32` | live setpoint update during the `MANUAL` infinite HOLD |
| `/palpation/forget_contact` | `std_msgs/Empty` | drops the learned contact for the current home (fired by unchecking **Home conhecida**); the next descent crawls from the start and re-learns |
| `/load_cell/voltage` | `std_msgs/Float32` | raw load-cell voltage (V) |
| `/load_cell/force` | `std_msgs/Float32` | calibrated force (N, compression +) |
| `/load_cell/force_net` | `std_msgs/Float32` | **tare-compensated** force (published by the GUI; consumed by the explorer/logger) |
| `/load_cell/calibrated` | `std_msgs/Bool` | calibration loaded |
| `/ft_sensor/wrench` | `geometry_msgs/WrenchStamped` | FA7155 only — six filtered, tared channels (N, N·m) |
| `/ft_sensor/wrench_raw` | `geometry_msgs/WrenchStamped` | FA7155 only — six channels straight off the wire |
| `/touch_sensor/value` | `std_msgs/Float32` | touch-sensor reading |
| `/touch_sync/data` | `touch_pack_msgs/SyncedTouch` | synchronized force × touch pair (50 Hz) |

---

## Triggering palpation from the terminal

```bash
# Touch mode — 3 touches at 2 N
ros2 topic pub --once /palpation/start touch_pack_msgs/msg/PalpationStart \
  "{mode: 'TOUCH', force_n: 2.0, depth_mm: 30.0, repeats: 3,
    approach_speed_mms: 50.0, speed_factor_pct: 10.0}"

# Slide mode — 50 mm along +Y at 10 mm/s
ros2 topic pub --once /palpation/start touch_pack_msgs/msg/PalpationStart \
  "{mode: 'SLIDE', force_n: 2.0, depth_mm: 30.0, speed_mms: 10.0,
    slide_dist_mm: 50.0, slide_dir: '+Y', repeats: 1,
    approach_speed_mms: 50.0, speed_factor_pct: 10.0}"

# Matrix mode — 2×2 grid with 5 mm pitch at 1.5 N (the origin is discovered
# by the robot itself, so (0,0) is NOT in the list)
ros2 topic pub --once /palpation/start touch_pack_msgs/msg/PalpationStart \
  "{mode: 'MATRIX_MAP', force_n: 1.5, depth_mm: 30.0,
    approach_speed_mms: 50.0, speed_factor_pct: 10.0,
    safe_z_mm: 10.0, transit_speed_mms: 20.0, grid_shape: 'SQUARE',
    waypoints: [{x: 0.005, y: 0.0}, {x: 0.005, y: 0.005}, {x: 0.0, y: 0.005}]}"

# Monitor the FSM
ros2 topic echo /palpation/status

# Stop / pause
ros2 topic pub --once /palpation/stop  std_msgs/msg/String "data: 'stop'"
ros2 topic pub --once /palpation/pause std_msgs/msg/Bool   "data: true"
```

FSM phases: `IDLE · HOME · DESCENDING · HOLD · SLIDING · RETRACT · DONE · ABORTED`

---

## Kinematics (`kinematics.py`)

FK and Jacobian for the selected end effector:

```python
T_TOUCH_TOOL_ATTACH  # palpation TCP — +162.2 mm in Z from Link6 (tcp_link)
T_HAND_ATTACH        # COVVI hand attachment (prosthesis coupler)
```

Two solvers share this geometry, for two different jobs:

| | `inverse_kinematics(p, approach)` | `manip3d.ik_step(q, p_target)` |
|---|---|---|
| Method | multi-seed (~16 candidates) + DLS refinement | one DLS step from the current pose |
| Cost | tens of ms | tens of µs |
| Continuity | may switch elbow/wrist branch | continuous by construction |
| Used by | `tactile_explorer` (poses planned offline) | the **3D Manipulation** tab (interactive drag @ 33 Hz) |

### Palpation TCP

The geometry lives in **one place**: [`urdf/touch_tool_tcp.urdf`](urdf/touch_tool_tcp.urdf).
`tactile_cell.launch.py` reads that file and injects it into the CR10 (it only
strips the standalone `world`/`Link6` scaffolding), so the simulated stack and
the standalone URDF can no longer drift apart.

The links come from a single CAD assembly,
[`cad/step/MONTAGEM_COMPLETA.step`](../../cad/step) — the solids are already
positioned against each other, and Z = 0 in that file *is* the CR10 flange
face. The robot wrist is in the assembly as a mounting reference only: the mesh
generator drops it, so it counts neither towards the mass nor towards the
origin.

| Z range (mm) | Link | CAD solid | Material |
|---|---|---|---|
| 0.0 … 18.5 | `coupler_robot_link` | `acoplador_robo` | printed, blue |
| 15.5 … 91.7 | `load_cell_link` | `celula_carga_100kg` | alloy steel, S-beam |
| 88.7 … 118.7 | `coupler_tool_link` | `acoplador_tool` | printed, blue |
| 101.7 … 157.7 | `touch_tool_link` | `touch_tool` | printed, blue |
| 147.7 … 161.7 | `tool_tip_link` | `ponteira_D_sensor_5x5` | printed, blue |
| 161.7 … **162.2** | `tool_tip_link` | `sensor_5x5_pad` | tactile laminate |

```
Link6 → coupler_robot (+0) → load_cell (+15.5) → coupler_tool (+73.2)
      → touch_tool (+13.0) → tool_tip (+46.0) → tcp_link (+14.5)  = +162.2 mm
```

`tcp_link` sits on the **contact face of the laminate**. The overlapping Z
ranges are the mechanical fits (the S-beam's ends thread into both couplers,
the touch tool's shaft goes into the tip's sleeve), so each link only carries
collision geometry for what is actually *exposed*.

**The 5×5 tactile sensor is on this tip.** Tip D was designed for it: its head
is 22.4 × 24.9 mm against the laminate's 17 × 19.47 mm, so the laminate is
fully supported — no edge overhang, unlike tip F (15.4 × 17.4 mm) of the
FA7155 stack. The three laminate layers (flex / piezoresistive / flex, 0.5 mm
together) are glued and become a single link.

Meshes and inertias are regenerated from the assembly with:

```bash
python3 src/touch_pack/scripts/gen_tcp_meshes_from_step.py            # load_cell (default)
python3 src/touch_pack/scripts/gen_tcp_meshes_from_step.py --stack ft6
```

It writes the STLs into `meshes/`, prints the `<inertial>` blocks and the TCP
height. Total assembly: **0.6034 kg**, CoM at **Z = +58.7 mm** from the flange
(weight 5.92 N). Printed-part density is 950 kg/m³; the S-beam is integrated at
7850 kg/m³ — here the geometry knows more than the catalogue, because the STEP
carries the S cutouts (60.5 cm³ against the 74.0 cm³ envelope) and integrating
gives 474.8 g, better than the datasheet's "≈0.5 kg".

> **Changing the TCP length touches three files**: `urdf/touch_tool_tcp.urdf`
> (the source of truth), `kinematics.T_TOUCH_TOOL_ATTACH`, and the
> `gravity_compensation.CoG` block of `config/tactile_controllers.yaml`.
>
> **The geometry follows the cell that is bolted on, not the driver that is
> running** — `force_sensor:=ft6` picks the receiver, it does not move the TCP.
> Between 18/08/2026 and 26/08/2026 this stack was the FA7155's, at 67.7 mm;
> the S-beam is **94.5 mm longer**. Joint-space HOME poses and learned contact
> depths saved under `~/.config/touch_pack/` during that window put the tip that
> much lower — **re-teach HOME before the first run**. The `tool_tcp_mm` stamp
> written into those files says which tool taught them, and the GUI warns on
> load.

Real arm ↔ URDF convention: joint offsets are handled in `kinematics.py` (joints 2 and 4 have an offset relative to DH); `_HOME_Q` and `JOINT_MIN/MAX` are also in the URDF convention.

---

## MIRROR mode — mirroring the real robot

In MIRROR, the commands published on `/cr10_group_controller/joint_trajectory` reach the real CR10:

- **Palpation running**: `ServoJ` at 33 Hz with the position from `/joint_states` (minimal latency for force control).
- **Manual jog (IDLE)**: `MovJ` with an 80 ms debounce from the last published point.
- **Drag Teach**: polls the real arm at 33 Hz and publishes into Gazebo (mirrors the manual motion).
- **No GUI** (`no_gui:=true`): `mirror_node` reproduces the core of that behavior.

The real arm's velocity is set by `SpeedFactor(%)` — synchronized with the GUI slider (forced to 10 % during palpation for safety).

<p align="center">
  Diagram of the two directions of the bridge: Sim-to-Real where the simulator commands, and Real-to-Sim where the hardware commands
</p>
<p align="center"><em>Only one direction is active at a time, selected by mode. <strong>Sim-to-Real</strong>: the same goal moves the virtual model and the real equipment at once. <strong>Real-to-Sim</strong>: the hardware has authority, which is what makes drag teach possible (controller in REMOTE mode). Diagram labels are in Portuguese.</em></p>

### Startup synchronization (`real_pose_sync`)

<p align="center">
  Flow diagram: at startup the system reads the real arm pose over TCP/IP and drives Gazebo to it in about 3 seconds, or keeps the default URDF pose if the robot is unreachable
</p>
<p align="center"><em>The twin is born synchronized: at launch the real CR10 pose is read over TCP/IP (read-only) and Gazebo is driven to it (~3 s). If the robot is off or unreachable, the default URDF pose is kept and the system still comes up.</em></p>

<p align="center">
  The real CR10 with the touch tool beside a monitor showing Gazebo with the simulated arm in the same pose
</p>
<p align="center"><em>The same initial state on both sides — real arm and Gazebo — right after startup synchronization.</em></p>

### Measuring the mirroring latency

<p align="center">
  Diagram of the latency measurement: the simulated and physical joint-angle series are resampled on a common clock and cross-correlated; the correlation peak gives the time shift
</p>
<p align="center"><em>Latency is measured by cross-correlating the simulated joint series with the physical one (125 Hz) on a common <code>time.monotonic</code> clock. The peak gives Δt; the sign of the lag tells which side leads — sim ahead (Sim→Real) or real ahead (Real→Sim). See <code>latency_probe.py</code>. Diagram labels are in Portuguese.</em></p>

---

## 6-axis load cell (FA7155 over RS485)

The **alternative** to the axial 100 kg cell, selected with
`force_sensor:=ft6`. **There is no firmware of ours in this path**: the sensor
is an RS485 talker that starts streaming the moment it is powered, a USB↔RS485
converter (ZK-U485/CH340) bridges it to the PC, and `ft_receiver` is the
driver. Running it means the XIAO + HX711 chain comes out entirely — *and so
does the mechanical stack*: the FA7155 is 94.5 mm shorter, so
`urdf/touch_tool_tcp.urdf` and `kinematics.T_TOUCH_TOOL_ATTACH` have to change
with it (see **Palpation TCP**). The `force_sensor` argument alone only swaps
the driver.

### Wiring

| FA7155 wire | goes to |
|---|---|
| red `VCC` | **+24 V from an external supply** (12–48 V) |
| black `GND` | supply negative **and** the converter's `GND` (common reference) |
| yellow `485_A` | converter `A` |
| green `485_B` | converter `B` |

The converter's `+5V` pin **cannot** power the cell — it is there to feed 5 V
logic, and the FA7155 needs 24 V. Skipping the common ground is the usual cause
of a link that opens the port and then stays silent.

### Frame (manual §4.2)

28 bytes: `53 54` header, six little-endian `float32` in the order
`fx fy fz mx my mz` (N and N·m, factory-calibrated), then CRC-16/MODBUS over the
**first 26 bytes, header included**, transmitted little-endian. 115200 baud,
250 Hz. Since the sensor never stops talking, the driver enters mid-frame and
resyncs on header + CRC — `0x53 0x54` also occurs inside the data, so the CRC is
what confirms the alignment, and a false header advances **one** byte, not 28.

At 115200 baud a 28-byte frame costs 2.43 ms, so the link tops out near
**411 Hz**. A unit ordered at the series' 500–1000 Hz option does not fit and
will arrive shredded.

### Bench bring-up

```bash
python3 src/touch_pack/scripts/ft_probe.py --list   # which port is the converter
python3 src/touch_pack/scripts/ft_probe.py --raw    # bytes arriving at all?
python3 src/touch_pack/scripts/ft_probe.py --zero   # live table of the 6 axes
```

Press the tip against the bench and watch which channel moves. That decides the
two parameters that adapt the cell to the existing force loop:

| parameter | default | meaning |
|---|---|---|
| `ft_force_axis` | `z` | which channel plays the role of the old axial cell |
| `ft_force_sign` | `-1.0` | sign that puts it in the system's **compression-positive** convention |

`Fz+` points *out* of the tool face (manual, figure 2), so pressing in reads
negative — hence the `-1.0`. **Confirm it on the bench before the first run:** a
flipped sign means the safety cutoff sees tension where there is compression.

### Running it

It is **not** the default — ask for it explicitly:

```bash
ros2 launch touch_pack tactile_cell.launch.py end_effector:=touch_tool sensor:='5' force_sensor:=ft6
```

`ft_port:=COM5` (or `/dev/ttyUSB0`) pins the port when more than one USB-serial
adapter is present. Both nodes publish `/load_cell/force_net`, so **only one
may run** — two publishers on the safety loop's topic make the explorer
regulate against the average of two cells, which is why an unrecognized
`force_sensor` value falls back to `load_cell` (the cell that is actually on
the bench) rather than silently starting the driver for a board that is not
plugged in.

Everything downstream is unchanged: `/load_cell/force_net` still carries a
tare-compensated, compression-positive force in newtons through the same
median + One-Euro filter, so the force-modulation control, the 15 N abort and
the contact detection need no changes. There is **no calibration file** —
`/load_cell/calibrated` now means "valid frames are arriving", and the tare
(which zeroes all six axes) is the only zeroing left on the host side. The
FA7155 has no zero command in active mode, so `/load_cell/rezero` from the GUI
redoes the tare.

One caveat for the CSVs: in `/load_cell/sample_net` the `voltage_raw` /
`voltage` fields carry the control-axis force **in newtons**, not volts —
columns `lc_voltage_raw_v` / `lc_voltage_v` must be read as newtons in runs made
with this cell. Zeroing them would have been truer to the name but would throw
away the unfiltered value, which is the whole reason those fields exist.

---

## Load cell (XIAO ESP32C6 + HX711)

**This is the default cell** — the plain launch already brings up
`force_receiver`:

```bash
ros2 launch touch_pack tactile_cell.launch.py end_effector:=touch_tool sensor:='5'
```

`lc_port:=/dev/ttyACM0` pins the port when more than one ESP32 is on the
machine; empty (the default) auto-detects by the Espressif VID `0x303A`.

Unlike the FA7155, this path has **firmware of ours** in it
(`sensors/ForceDriver/`, PlatformIO) and it needs a **calibration file** —
without one `force_receiver` publishes no `/load_cell/force_net` at all, on
purpose: the explorer then refuses the run for a missing reading instead of
regulating against a line nobody checked. The repo ships one:
`sensors/load_cell_calib.json`, the 7-point calibration of the cell on the
bench, and that versioned file **is** the path both the receiver and the wizard
use (`constants.LC_CALIB_FILE`). One file, not a copy in `~/.config` and
another in the repo — that pair was how you end up calibrating one and
measuring with the other.

The GUI's **Load Cell** tab is the axial cell's: **Reading** (live force,
voltage, both zeros) and **Calibration** (the wizard).

**Transport: USB serial only.** The UDP/WiFi path was removed on 27/07/2026 —
along with the ESP's static IP, port 8080, the `FRCV` discovery on 8090 and OTA
flashing. The radio cost 1–6.6 % packet loss every 10 s, delivered in bursts
(jitter, which in a force loop is worse than mean latency) and injected noise
into the HX711 front end. **The XIAO must be on the USB cable — there is no
network fallback.**

`force_receiver` is the *sole owner* of the serial port (a tty admits one
reader), auto-detecting it by the Espressif VID `0x303A`. Every other node —
including `palpation_gui` — consumes `/load_cell/voltage`. The firmware re-zero
goes through the `/load_cell/rezero` topic, which `force_receiver` relays as
`'Z'` on the wire.

**Line format**: `F,<seq>,<t_us>,<v_sensor>\n`. `v_sensor` is the bridge voltage
*after* the PGA; `t_us` is the ESP's `micros()` and gives the receiver the real
`dt` (so the HX711 rate needs no configuring). Lines starting with `#` are
heartbeats and are ignored by the parser.

**Resolution** (24 bits, AVDD = 3.3 V, gain 128):

| quantity | value |
|---|---|
| full-scale at the bridge | ±0.5·AVDD/128 = **±12.89 mV** |
| 1 LSB in the ×PGA domain | AVDD/2²⁴ = **196.70 nV** |
| 1 LSB referred to the bridge | 196.70 nV/128 = **1.537 nV** |
| 1 LSB in force (100 kg / 2 mV/V cell) | **≈ 0.23 mN** |

The 0.23 mN figure is quantization only; the real floor is HX711 noise (tens of
counts), roughly 1 mN rms filtered.

**Sampling rate**: set by the HX711 `RATE` pin (pin 15) — GND = 10 Hz,
DVDD = 80 Hz. The stock red boards tie it to GND, and ~10 Hz is what we measure.
At 10 Hz no filter tuning yields a fast response (median-of-3 alone costs
100 ms). Cut the RATE→GND trace and bridge pin 15 to DVDD; nothing in software
needs to change.

**Two different zeros, and they are not interchangeable.**
`/load_cell/tare` is the **host** tare: a software subtraction inside
`force_receiver`, redone automatically at startup once the window is stable and
the resting reading sits near the calibration's V₀ (that second guard is what
stops it from zeroing a real load already resting on the tip). `/load_cell/rezero`
is the **firmware** zero: it becomes the byte `'Z'` on the wire and makes the
MCU re-collect the bridge's resting offset, which is the only way to take
*thermal* drift out of the equation. The host tare subtracts the symptom; `'Z'`
rebuilds the reference.

**Sign convention**: calibration is performed **in compression** (cell pointing
up, standard masses resting on it), so `force = (v − ref)/slope` is positive in
compression and negative in tension, whatever the wiring polarity — `slope`
absorbs it. Single source of truth: `constants.lc_force_n`, used by the
receiver, by the calibration wizard and by any offline reprocessing — so the
newton on the plot and the newton in the log are the same newton. The file
itself has a single reader too, `constants.lc_load_calibration`, which is
where the `intercept` / `zero_voltage` alias is resolved once instead of in
every consumer.

**The fit holds V₀ fixed** (`constants.lc_fit_slope`): `slope = Σ((v−V₀)·F)/ΣF²`
over the mass points, with V₀ the measured no-load average. It is not a free
two-parameter regression, and the difference is not cosmetic — on the 7 points
that came with this cell, the free fit returns V₀ = −4.29e-5 V against the
+2.77e-5 V actually measured, and a slope 0.8 % away. A measured no-load
average is far better determined than anything a regression can infer from the
loaded points, and 0.8 % of force scale never shows up as a failure, only as
one run that disagrees with another. This is the method that produced the
calibration shipped in the repo, and `test_force_receiver.py` locks a refit of
the stored points against the stored slope.

The calibration is read from `sensors/load_cell_calib.json` and reloaded
periodically (5 s timer, by mtime — the receiver owns the serial port and must
not be restarted just to pick up a new fit); it is produced by the wizard in
the **Calibration** sub-tab of the Load Cell tab, which writes that same file.
Override with `lc_calib_path:=<file>` on the node if you need to try a fit
without touching the versioned one.

---

## Persistent files

| Path | Contents |
|---|---|
| `~/.config/touch_pack/robot.json` | IPs (hand/arm) + last mode (SIM_ONLY/MIRROR) |
| `~/.config/touch_pack/home_pose.json` | custom arm home |
| `~/.config/touch_pack/load_cell_calib.json` | calibration slope/intercept |
| `~/.config/touch_pack/palpation_params.json` | last palpation parameters (including the mode) |
| `~/.config/touch_pack/poses.json` | recorded poses and motions |
| `<repo>/sensors/Data/` | palpation data and the force+touch stream |

---

## Dependencies

```bash
sudo apt install ros-humble-admittance-controller \
                 ros-humble-kinematics-interface-kdl \
                 ros-humble-force-torque-sensor-broadcaster
pip install "numpy<2" matplotlib pyserial   # matplotlib/pyserial: Sensors tab (optional)
```

> Without `matplotlib`/`pyserial` the GUI still works in a degraded mode (the Sensors tab is disabled; the rest of the palpation works normally).

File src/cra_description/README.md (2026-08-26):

# cra_description

Package holding the **URDF/Xacro and meshes of the Dobot CR10 arm** (CR10A model, 6-DOF). Extracted from the official Dobot repository [`DOBOT_6Axis_ROS2_V4`](https://github.com/Dobot-Arm/DOBOT_6Axis_ROS2_V4) — only this package is used; the others (cr3, cr5, cr7, MoveIt, nova2, etc.) can be discarded.

<p align="center">
  Dobot CR10 arm (cra_description URDF) positioned above the pick station in Gazebo
</p>
<p align="center"><em>URDF of the <strong>Dobot CR10</strong> (6-DOF) loaded into Gazebo Classic from this package's <code>cr10_robot.xacro</code>.</em></p>

<p align="center">
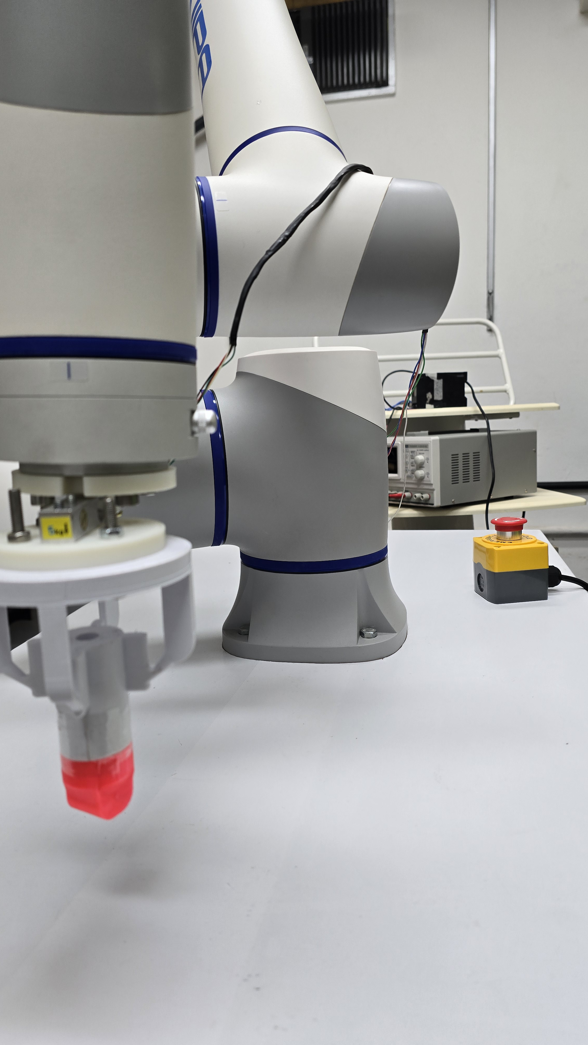
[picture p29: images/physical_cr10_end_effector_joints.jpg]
Close-up of the real CR10 wrist joints and tool flange, with an end effector bolted on and the emergency stop in the background
  
</p>
<p align="center"><em>The real arm this URDF models: the CR10 wrist (joint4–joint6) and the tool flange the project's end effectors bolt onto.</em></p>

---

## Contents

```
cra_description/
├── urdf/
│   └── cr10_robot.xacro          Main CR10 URDF (6 joints + ros2_control)
├── meshes/
│   └── *.stl / *.dae             Visual and collision meshes for each link
└── package.xml
```

---

## How to obtain it

```bash
cd ~/cr10twin/src
git clone https://github.com/Dobot-Arm/DOBOT_6Axis_ROS2_V4.git

# Keep only cra_description
cd DOBOT_6Axis_ROS2_V4
find . -mindepth 1 -maxdepth 1 ! -name 'cra_description' -exec rm -rf {} +

# Or move it straight into src/ and delete the clone
cd ~/cr10twin/src
mv DOBOT_6Axis_ROS2_V4/cra_description ./cra_description
rm -rf DOBOT_6Axis_ROS2_V4
```

---

## Use in the project

`cr10_robot.xacro` is processed at launch time by the `grasp_ml_pack` and `touch_pack` packages:

```python
import xacro
doc = xacro.parse(open(cr10_xacro_path))
xacro.process_doc(doc)
cr10_urdf = doc.toxml()
```

The resulting URDF gets the end effector (COVVI hand or touch_tool) injected into it and is published to `robot_state_publisher`. No modifications are made to the package's original files.

---

## Kinematic parameters (joints in URDF convention)

| Joint | xyz (m) | rpy (rad) |
|---|---|---|
| joint1 | `(0, 0, 0.1765)` | `(0, 0, 0)` |
| joint2 | `(0, 0, 0)` | `(π/2, π/2, 0)` |
| joint3 | `(-0.607, 0, 0)` | `(0, 0, 0)` |
| joint4 | `(-0.568, 0, 0.191)` | `(0, 0, -π/2)` |
| joint5 | `(0, -0.125, 0)` | `(π/2, 0, 0)` |
| joint6 | `(0, 0.1084, 0)` | `(-π/2, 0, 0)` |

The joint sign convention in the URDF is identical to the Dobot TCP/IP V4 firmware — offset `_URDF_DOBOT_OFFSET = np.zeros(6)` in `kinematics.py`.

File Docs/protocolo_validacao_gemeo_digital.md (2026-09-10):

# Plano de correção do artigo + protocolo de coleta

**Projeto:** cr10twin / `touch_pack` · **Bancada:** Dobot CR10 (`192.168.5.2`) + mão
COVVI (ECI `192.168.5.103`) · **Efetuador:** `end_effector:=hand`
**Artigo:** *From Simulation to Hardware: A Digital Twin as a Development Platform
for a Collaborative Robotic Arm and a Multi-Articulated Hand*

**Criado:** 10/09/2026 · **Revisado:** 10/09/2026 (dados recuperados, tabelas geradas)

---

## 1. Estado atual — o que já está resolvido

Os dados brutos das 7 capturas do artigo **foram recuperados da lixeira** e agora
vivem em `data/latency/` (versionado; ver o comentário no `.gitignore`). Com eles,
uma parte grande do parecer se fecha **sem bancada nenhuma**.

```bash
ros2 run touch_pack latency_report -- data/latency
# → data/latency/latency_summary.csv    (uma linha por par captura-junta)
# → data/latency/latency_tables.tex     (tabelas em IEEEtran, prontas)
```

### 1.1 Resultados já disponíveis

| Condição | N | \|Δt\| (ms) | MAE (°) | RMSE (°) | r mínimo |
|---|---|---|---|---|---|
| drag teach (amplitude 0,36–33,16°) | 17 | 71,54 ± 0,30 | 0,009 ± 0,007 | 0,024 ± 0,022 | 0,999976 |
| GUI jog (amplitude 2,86–3,87°) | 3 | 78,22 ± 1,42 | 0,116 ± 0,017 | 0,271 ± 0,050 | 0,995260 |

Por junta, na condição drag teach — **o atraso é o mesmo em todas as seis**, o que
sustenta empiricamente a afirmação de que ele é dominado pelo caminho de transporte
compartilhado e não pela dinâmica de cada junta:

| Junta | N | \|Δt\| (ms) | MAE (°) | erro máx (°) | r |
|---|---|---|---|---|---|
| joint1 | 3 | 71,6 ± 0,1 | 0,003 | 0,15 | 1,00000 |
| joint2 | 3 | 71,4 ± 0,2 | 0,006 | 0,18 | 0,99999 |
| joint3 | 4 | 71,4 ± 0,1 | 0,012 | 0,17 | 0,99999 |
| joint4 | 4 | 71,7 ± 0,5 | 0,011 | 1,09 | 0,99998 |
| joint5 | 2 | 71,3 ± 0,2 | 0,015 | 1,33 | 0,99999 |
| joint6 | 1 | 71,9 | 0,010 | 0,58 | 1,00000 |

**O argumento novo mais forte do artigo sai daqui:** sem compensar o atraso o RMSE
é 0,558°; compensando, cai para 0,024° — **23× menor**. Ou seja, o desacordo entre
gêmeo e braço físico é **atraso, não infidelidade**. O gêmeo reproduz a postura real
com fidelidade de centésimos de grau.

### 1.2 Unidade de análise

A reanálise usa o par **(captura, junta)**, não a captura. Cada junta que se moveu é
uma medição independente do mesmo acoplamento. É assim que 4 capturas de drag teach
viram 17 medições cobrindo duas ordens de grandeza de amplitude — variedade de
configuração de movimento a partir do que já foi coletado, que é metade do item 1
do parecer.

---

## 2. O achado que obriga a corrigir o texto

> **As duas latências publicadas (78,2 e 71,8 ms) medem o MESMO caminho de dados.**
> Não são Sim-to-Real e Real-to-Sim.

**Prova nos próprios dados:** os sete arquivos se chamam `latency_real_to_sim_*`.
Nas três capturas de "GUI jog", o `_result.json` traz
`direction_requested: sim_to_real` e `direction_detected: real_to_sim`. A ferramenta
avisou na hora da coleta.

**Causa no código:** em `MIRROR` com a fase de palpação `IDLE` — o estado durante o
jog manual — o `_mirror_poll_loop` chama `_mirror_follow_tick()`
(`palpation_gui.py:3155`), e esse tick lê o feedback do braço real e o **republica no
tópico de comando do Gazebo** (`:3363-3369`). Cada `MovJ` de jog abre uma janela de
*follow* real→sim de até 15 s (`:3006-3008`). Durante a captura, o Gazebo seguia o
braço físico.

Os ~6 ms de diferença entre as condições são amplitude de movimento, não direção.

### 2.1 Onde o Sim-to-Real de verdade acontece

| Caminho | Quando | Transporte | Contaminado pelo follow? |
|---|---|---|---|
| `_run_movement_once` (aba Poses & Motions) | execução de movimento salvo | `MovJ` por pose | **Não** — `_exec_movement_id` faz o poll loop pular o follow (`:3147`) |
| `_mirror_poll_loop` ServoJ | fase de palpação ATIVA | `ServoJ` 33 Hz de `/joint_states` | **Não** |
| jog por slider / manip 3D | fase `IDLE` | `MovJ` debounce 80 ms | **Sim** — mede real→sim |

### 2.2 O que dá para dizer sobre Sim-to-Real hoje

Uma estimativa por instante de início de movimento nas 3 capturas de GUI jog dá
**8 eventos entre 60 e 264 ms**. Indica que o caminho Sim-to-Real é algumas vezes
mais lento que o espelhamento (coerente com 80 ms de debounce + `MovJ` + rampa), mas
com esse espalhamento não é número de tabela. Some-se que a velocidade de pico do sim
chega a 49°/s enquanto a do real fica travada em 19,5°/s pelo `SpeedFactor` — os
perfis diferem, e o limiar de início já vicia a medida.

**Serve como justificativa do trabalho futuro. Não serve como resultado.**

---

## 3. Triagem do parecer

### 3.1 Fechado pela reanálise (sem bancada)

| Item do parecer | Como fecha |
|---|---|
| 6 — MAE/RMSE/erro máx/correlação/Δt por junta | Tabelas do §1.1, já geradas |
| 1 — mais configurações de movimento | 17 medições, 6 juntas, 0,36–33,16° |

### 3.2 Só texto e figura (sem bancada)

| # | O quê | Esforço |
|---|---|---|
| 1 | Corrigir os rótulos da Tabela II e da §Results — sem isso o item 2 não fecha e o erro é achável por qualquer revisor com acesso aos dados | 1 h |
| 2 | Figs. 4 e 5 estão **com legendas em português** num artigo em inglês (`fig_modos_sim_real.svg`, `fig_estado_inicial.svg`) | 1 h |
| 3 | `images/fig_latencia_metodo.svg` já existe, pronta, e **não está no artigo** — entra como painel do método | 30 min |
| 4 | Limitações: latência é **só do braço** (a mão nunca foi caracterizada), um objeto por arquétipo, sem repetição, sem forças/torques/reality gap | 1 h |
| 5 | Posicionamento vs. trabalhos anteriores: a tríade (abstração única + sincronização automática + bidirecionalidade). Precisa de passada de literatura | 3–4 h |
| 6 | Refazer a Fig. 8 com os dados reanalisados: painel do método + dispersão por junta | 2 h |

### 3.3 Precisa de bancada — **em ordem de prioridade**

| Prio | Bloco | Por quê nessa posição |
|---|---|---|
| **1** | **E — preensão** (§6) | **Único item do parecer que a reanálise não alcança.** E é o mais barato: ~90 min, zero código, zero ferramenta nova |
| 2 | B — Sim-to-Real (§5) | A direção que o artigo não mede. Exige a correção do §5.1 |
| 3 | D — sincronização inicial (§7) | Barato, objetiva a Fig. 5 |
| 4 | A — Real-to-Sim repetido (§4) | **Rebaixado**: a reanálise já entrega 17 medições. Só vale para repetibilidade da MESMA trajetória |
| 5 | C — ServoJ perfil casado (§8) | Opcional; mexe no laço crítico de segurança |

### 3.4 Não fazer

Forças de contato, torques e quantificação formal do *reality gap*. O próprio parecer
concede que fiquem como limitação.

---

## 4. Pré-voo (uma vez, no início do dia)

1. Controlador CR10 em **REMOTE** (`Settings → Operate Mode`, ou `http://192.168.5.2`).
2. Nenhuma outra sessão conectada ao robô — o `latency_probe` abre mais uma.
3. Mão COVVI energizada: `ping 192.168.5.103`.
4. Diretório da campanha, **fora** de `sensors/Data/` (que é `.gitignore`d):
   ```bash
   export ART=~/artigo_dados
   mkdir -p "$ART"/{A_real2sim,B_sim2real,C_servoj,D_sync,E_grasp}
   ```
   O `latency_probe` grava em `$TOUCH_PACK_DATA_DIR/latency/`; cada bloco define esse
   env var. Ao final, copie os `*_raw.csv` e `*_result.json` para `data/latency/` e
   rode o `latency_report` de novo.
5. Fumaça, com o robô parado (vai reclamar de amplitude — é o esperado):
   ```bash
   TOUCH_PACK_DATA_DIR=$ART/smoke ros2 run touch_pack latency_probe --ros-args \
       -p robot_ip:=192.168.5.2 -p duration_s:=10.0
   ```

---

## 5. Bloco B — Sim-to-Real (prioridade 2)

O comando nasce no gêmeo e vai aos dois destinos a partir do mesmo instante:
trajetória completa para o Gazebo, `MovJ` por pose para o CR10.

### 5.1 ⚠️ Bug que contamina este bloco — corrigir ANTES de coletar

O detector automático de drag (`palpation_gui.py:6166`) liga o drag sozinho quando vê
as juntas se moverem mais de 0,8° com **2 s** sem comando vindo do PC
(`DRAG_SILENCE_S = 2.0`, `:6106`). E `_run_movement_once` **não atualiza**
`self._last_robot_cmd_t` ao enviar o `MovJ` (`:4735-4740`) — só o jog por slider atualiza.

Resultado: ~2–3 s depois do início da execução, o detector conclui "movimento sem
comando do PC" e liga o drag. A partir daí `_mirror_poll_loop` testa
`if self._drag_enabled:` **antes** de `if self._exec_movement_id is not None:`
(`:3090` vs `:3147`) e passa a espelhar real→sim — a contaminação que este bloco
existe para evitar.

**Correção mínima**, em `_run_movement_once`, logo após `drv.mov_j_joint_deg(...)`:
```python
self._last_robot_cmd_t = time.monotonic()
```

**Enquanto não corrigir:** o sintoma é visível — o botão vira `✋ Drag (auto)` e a
barra de status mostra *"Physical drag detected"*. Se acontecer numa captura,
**descarte a captura**.

### 5.2 Preparar o movimento (uma vez; salvo em `~/.config/touch_pack/poses.json`)

Aba **Poses & Motions**, robô em `MIRROR`, **drag desligado**:

1. Capture 4 poses com **⌨ Sim**, bem separadas, dentro do envelope seguro:

   | Pose | joint1 | joint2 | joint3 | joint4 | joint5 | joint6 |
   |---|---|---|---|---|---|---|
   | P0 | 0 | 0 | −90 | 0 | 90 | 0 |
   | P1 | +25 | −10 | −75 | 0 | 90 | 0 |
   | P2 | 0 | −25 | −60 | +20 | 75 | 0 |
   | P3 | −25 | −10 | −75 | −20 | 105 | 0 |

   Valores de partida — ajuste ao espaço livre real, mas **anote os usados**.
2. **＋ Novo movimento** → `artigo_s2r` → P0→P1→P2→P3→P0.
3. `dur_s = 2.5` s, `speed_pct = 30`. Uma passagem = 12,5 s.

> O perfil do Gazebo (interpolação do `joint_trajectory_controller`) e o do CR10
> (`MovJ` com `SpeedFactor`) **não são o mesmo perfil** — declarar como limitação. Por
> isso a métrica principal aqui é o **atraso de início de movimento**, não o RMSE ao
> longo da trajetória.

### 5.3 Capturar (5 repetições)

```bash
TOUCH_PACK_DATA_DIR=$ART/B_sim2real ros2 run touch_pack latency_probe --ros-args \
    -p direction:=sim_to_real -p robot_ip:=192.168.5.2 -p duration_s:=28.0
```
Assim que aparecer `Capturando por 28 s`, aperte **↻ Loop** em `artigo_s2r`. Duas
passagens cabem na janela. Ao fim, **■ Stop**. Repita 5× → 10 passagens → **40
transições de pose**.

O probe vai avisar `ATENÇÃO: você pediu 'sim_to_real' mas o sinal indica ...` —
**ignore**. A correlação cruzada compara perfis diferentes aqui. O que vale é o
`*_raw.csv`.

---

## 6. Bloco E — Taxa de sucesso de preensão (PRIORIDADE 1)

Troca as duas fotos da Fig. 9 por taxa de sucesso com intervalo de confiança. Sem
código: comando pela GUI e uma planilha.

### 6.1 Montagem

- **Gabarito.** Marque com fita a posição exata do objeto na bancada, com o contorno
  da base e uma marca de orientação. Todas as tentativas partem da mesma geometria —
  sem isso a taxa mede a sua pontaria, não a preensão.
- **Poses salvas.** Na aba **Poses & Motions**, para cada objeto:
  `P_approach` (mão aberta na posição de pega) e `P_lift` (mesma pose, +100 mm em Z).
  Monte um movimento com as duas.
- **Fotografe o gabarito montado** — vira figura de método ou material suplementar.

### 6.2 Condições

| Cond. | Objeto | Grip COVVI | `eci_id` |
|---|---|---|---|
| G1 | garrafa (a mesma da Fig. 9a) | **Power** | 2 |
| G2 | cubo pequeno (o mesmo da Fig. 9b) | **Prec. Closed** | 5 |

Opcionais, se sobrar tempo (fortalecem a generalização sem bancada nova):
G3 = lata cilíndrica / **Cylinder** (8) · G4 = cartão / **Key** (6).

### 6.3 Sequência da tentativa

1. Objeto no gabarito. Mão em **Glove** (aberta).
2. Executa o movimento até `P_approach`.
3. Aba **Manual Control**, card *COVVI Grips*: seleciona o grip da condição, **✓ Apply**.
4. Aguarda 2 s (fechamento).
5. Executa até `P_lift`. **Segura 5 s.**
6. *(robustez, opcional)* rotaciona `joint6` ±45° e volta.
7. Desce, aplica **Glove**, remove o objeto, recoloca no gabarito.

### 6.4 Critério de sucesso — fixar ANTES de começar, nunca depois

> **Sucesso** = o objeto permanece preso durante os 5 s de sustentação a 100 mm, sem
> escorregar mais de 10 mm em relação à mão e sem cair.

**N = 20 por condição.** Com 20/20 o intervalo de Wilson 95 % é **[83,9 %, 100 %]** —
suficiente para o artigo. Com menos de 20 o intervalo fica largo demais para valer a pena.

### 6.5 Planilha

`$ART/E_grasp/grasp_trials.csv`:
```csv
trial,condicao,objeto,grip,eci_id,sucesso,modo_falha,observacao
1,G1,garrafa,Power,2,1,,
2,G1,garrafa,Power,2,0,escorregou_na_subida,
```
`modo_falha` ∈ {`sem_contato`, `escorregou_no_fechamento`, `escorregou_na_subida`,
`escorregou_na_rotacao`, `objeto_deslocado_na_aproximacao`}.

Os modos de falha valem tanto quanto a taxa: são eles que sustentam a seção de
limitações e apontam se o limite é geometria, força de fechamento ou complacência.

### 6.6 Fotos novas para a Fig. 9

- **JPEG, não HEIC.** `images/` já tem `.HEIC` que o LaTeX não lê — o artigo usa as
  versões `.jpg` convertidas. Configure a câmera para JPEG e evite a conversão.
- **Mesma posição, altura e enquadramento de câmera nos dois (ou quatro) painéis.**
  Painéis comparáveis são metade do que o revisor pediu ao falar da Fig. 9. Um tripé,
  ou uma marca de fita no chão, resolve.
- **Fotografe durante os 5 s de sustentação, com o objeto no ar.** Uma foto com o
  objeto apoiado na mesa não prova preensão — prova contato.
- **Fundo neutro e limpo.** Tire da cena tudo que não for braço, mão e objeto.
- **Uma foto por condição, no mesmo instante do ensaio** (meio da sustentação).
- Se fizer G3/G4, a Fig. 9 vira um painel 2×2 — planeje o enquadramento para os
  quatro ficarem iguais.
- Fotografe também **uma falha representativa**, se ocorrer. Vale mais para a seção
  de limitações do que qualquer parágrafo.

---

## 7. Bloco D — Sincronização inicial (Fig. 5)

Troca o "cerca de três segundos" por curva de convergência medida e erro residual por
junta, em 10 subidas com poses de partida diferentes. O `real_pose_sync` roda em
**todo** launch, independente do `control_mode` (`tactile_cell.launch.py:497,635`).

Para cada uma das 10 repetições:

1. Leve o braço real a uma pose diferente. Anote.
2. **Terminal 2 primeiro** (o probe precisa gravar antes de o Gazebo subir):
   ```bash
   TOUCH_PACK_DATA_DIR=$ART/D_sync ros2 run touch_pack latency_probe --ros-args \
       -p robot_ip:=192.168.5.2 -p duration_s:=60.0
   ```
3. **Terminal 1**, imediatamente depois:
   ```bash
   ros2 launch touch_pack tactile_cell.launch.py \
       end_effector:=hand control_mode:=sim_only robot_ip:=192.168.5.2
   ```
4. Deixe o probe fechar sozinho, depois derrube o launch.

O braço real fica **parado** durante a sincronização — só o gêmeo se move. O número de
latência dessas capturas **não tem significado e deve ser descartado**. O que importa é
o `*_raw.csv`: nele está a série do Gazebo convergindo sobre a série constante do real.

---

## 8. Blocos A e C (prioridade baixa)

### 8.1 Bloco A — Real-to-Sim repetido

**Rebaixado**: o §1.1 já entrega 17 medições em 6 juntas e duas ordens de grandeza de
amplitude. O único ganho restante é repetir a *mesma* trajetória — e uma trajetória
conduzida à mão não repete.

Se for fazer: launch em `control_mode:=mirror`, **✋ Drag ON**, e
```bash
TOUCH_PACK_DATA_DIR=$ART/A_real2sim ros2 run touch_pack latency_probe --ros-args \
    -p direction:=real_to_sim -p robot_ip:=192.168.5.2 -p duration_s:=20.0
```
Matriz sugerida, 2 repetições cada: T1 joint1 ±25° lento · T2 joint1 ±25° rápido ·
T3 joint5 ±25° lento · T4 joint1+2+3 ±15° · T5 joint4 ±5° (baixa amplitude de propósito).
Aceite: `peak_corr ≥ 0,95` e `movement_amp_deg ≥ 2,0` (T5: `≥ 0,5`).

> **Automação possível.** `_toggle_drag` é só uma flag de software
> (`palpation_gui.py:4550-4571`) — não põe o CR10 em modo drag; quem libera os motores
> é o botão físico do braço. Com a flag ligada e o botão **não** pressionado, o braço
> continua sob servo, e um `MovJ` enviado direto pelo driver o move enquanto o
> `_mirror_poll_loop` republica o feedback de 125 Hz no Gazebo (`:3091-3126`) — o mesmo
> ramo de código do drag teach, com trajetória repetível. Guarda: `_mirror_movj_send`
> **desliga** o drag (`:2999-3001`), então o runner tem de chamar
> `drv.mov_j_joint_deg()` direto.

### 8.2 Bloco C — Sim-to-Real com perfil casado

O `mirror_node` só faz `ServoJ` streaming com a fase publicada em `/palpation/status`
diferente de `IDLE`/`DONE`/`ABORTED` (`mirror_node.py:274-280`). No `end_effector:=hand`
o modo Palpação é bloqueado (`palpation_gui.py:1927`) e o explorer publica `IDLE` a
10 Hz sem parar (`tactile_explorer.py:1788`). Contorno sem alterar código:

```bash
# T1 — plataforma SEM mirror e SEM GUI
ros2 launch touch_pack tactile_cell.launch.py \
    end_effector:=hand control_mode:=sim_only no_gui:=true robot_ip:=192.168.5.2
# T2 — mirror com o status remapeado
ros2 run touch_pack mirror_node --ros-args \
    -p robot_ip:=192.168.5.2 -r /palpation/status:=/latency/phase
# T3 — CONFIRME que sim e real concordam antes de armar o ServoJ
ros2 topic echo /joint_states --once
```

> ⚠️ **Segurança.** O primeiro `ServoJ` descarrega a diferença sim↔real inteira num
> único tick de 30 ms, **sem rampa** — é o que o pré-home da GUI existe para evitar
> (`palpation_gui.py:3172-3180`). Só publique a fase ativa depois de confirmar
> divergência **< 0,3°** em todas as juntas. Mão no botão de emergência.

```bash
# T3 — arma o ServoJ
ros2 topic pub -r 10 /latency/phase touch_pack_msgs/msg/PalpationStatus "{phase: 'TRANSIT'}"
# T4 — captura
TOUCH_PACK_DATA_DIR=$ART/C_servoj ros2 run touch_pack latency_probe --ros-args \
    -p direction:=sim_to_real -p robot_ip:=192.168.5.2 -p duration_s:=20.0
# T5 — move o gêmeo (primeiro ponto = pose ATUAL, senão o braço salta)
ros2 topic pub --once /cr10_group_controller/joint_trajectory \
  trajectory_msgs/msg/JointTrajectory \
  "{joint_names: [joint1,joint2,joint3,joint4,joint5,joint6],
    points: [
      {positions: [ 0.35, 0.0, -1.57, 0.0, 1.57, 0.0], time_from_start: {sec: 4}},
      {positions: [-0.35, 0.0, -1.57, 0.0, 1.57, 0.0], time_from_start: {sec: 9}},
      {positions: [ 0.35, 0.0, -1.57, 0.0, 1.57, 0.0], time_from_start: {sec: 14}},
      {positions: [ 0.00, 0.0, -1.57, 0.0, 1.57, 0.0], time_from_start: {sec: 18}}]}"
```
Ao terminar, **mate o T3 antes de tudo** (fase volta a `IDLE`, o ServoJ para).

---

## 9. Análise

Tudo é pós-processamento dos `*_raw.csv`, pelo `latency_report`. Ele já faz, por par
(captura, junta): estimativa do atraso por correlação cruzada com refino parabólico,
**compensação do atraso**, e então MAE, RMSE, erro máximo e correlação de Pearson.

A compensação é o ponto todo: sem ela o "erro" é dominado pelos ~71 ms e não diz nada
sobre fidelidade cinemática.

**Ainda não implementado no `latency_report`** (some quando os blocos rodarem):

- **Bloco B** — atraso de **início de movimento**: para cada transição de pose, o
  instante em que |velocidade| de cada série cruza 0,5 °/s pela primeira vez. 40
  eventos → média ± desvio. O RMSE ao longo da trajetória vai separado e rotulado como
  *discrepância de perfil*, não como erro de rastreamento.
- **Bloco D** — tempo até o erro sim↔real cair abaixo de 0,5° e nele permanecer, e erro
  residual por junta na média dos 2 s finais.

**Tabelas do artigo:**

| Tabela | Fonte | Status |
|---|---|---|
| Latência por condição | `latency_tables.tex` | ✅ pronta |
| Fidelidade cinemática por junta | `latency_tables.tex` | ✅ pronta |
| Preensão: N, sucessos, taxa, IC 95 % Wilson, modos de falha | Bloco E | ⬜ falta coletar |
| Sincronização inicial: tempo de acomodação, erro residual | Bloco D | ⬜ falta coletar |

---

## 10. Ferramentas

| O quê | Onde | Status |
|---|---|---|
| `latency_report` — reanálise, resumo CSV e tabelas LaTeX | `touch_pack/latency_report.py` | ✅ escrito e testado (`test/test_latency_report.py`) |
| **Correção do §5.1** — `_last_robot_cmd_t` em `_run_movement_once` | `palpation_gui.py` | ⬜ **bloqueia o Bloco B**. Uma linha |
| Métricas de início de movimento (Bloco B) e de acomodação (Bloco D) | `latency_report.py` | ⬜ só necessário se os blocos rodarem |
| Runner de campanha na GUI (aba automatizando A/B/C) | módulos novos | ⬜ ~1–1,5 dia. Só se pagar em campanha repetida |
| Probe de latência da **mão** (`/joint_states` × `DigitPosnAll`) | nó novo | ⬜ fora de escopo. A latência publicada é só do braço |

---

## 11. Orçamento de bancada

| Prio | Bloco | Tempo |
|---|---|---|
| — | Pré-voo | 20 min |
| **1** | **E — preensão (40 tentativas + fotos)** | **90 min** |
| 2 | B — Sim-to-Real (5 × 28 s + montar poses) | 60 min |
| 3 | D — sincronização (10 × 60 s) | 40 min |
| 4 | A — Real-to-Sim repetido | 45 min |
| 5 | C — ServoJ | 45 min |

**Se der para fazer só uma coisa: o Bloco E.** É o único item do parecer que a
reanálise não alcança, e é o mais barato de todos.

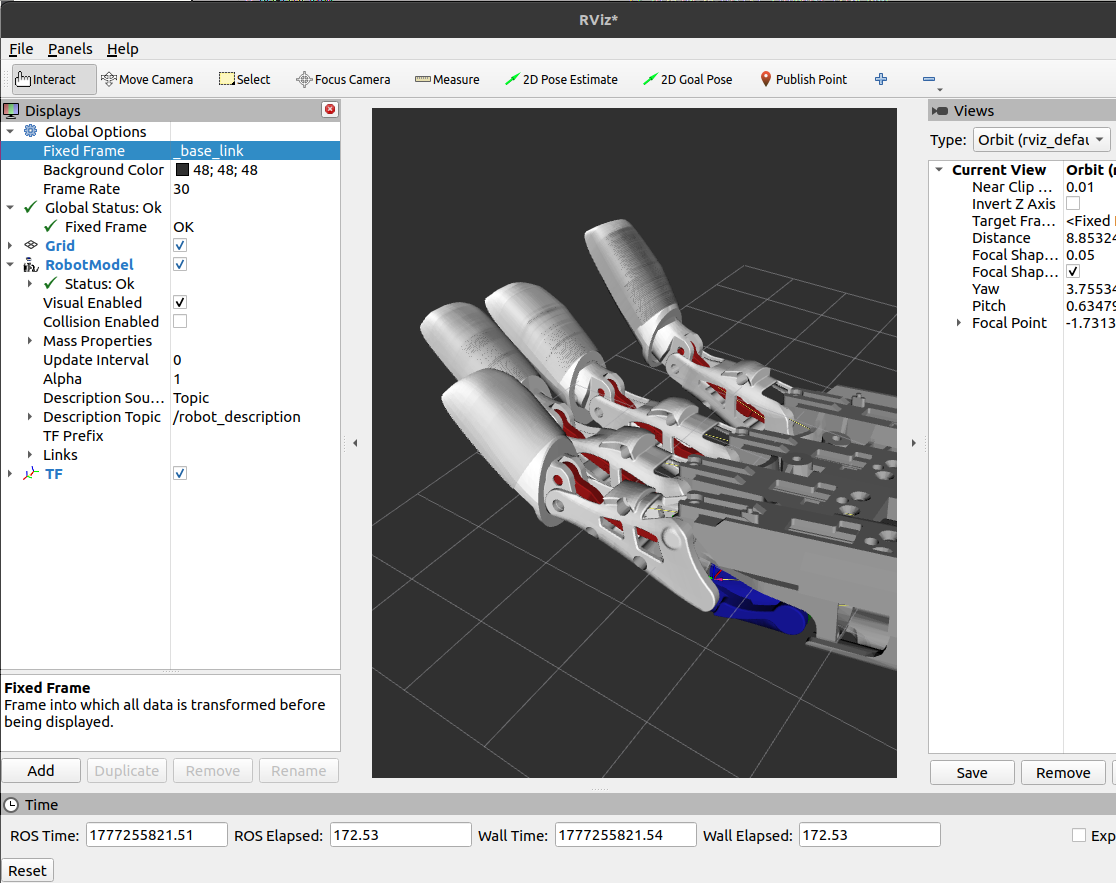
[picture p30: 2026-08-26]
images/covvi_hand_3d_design_internal.png

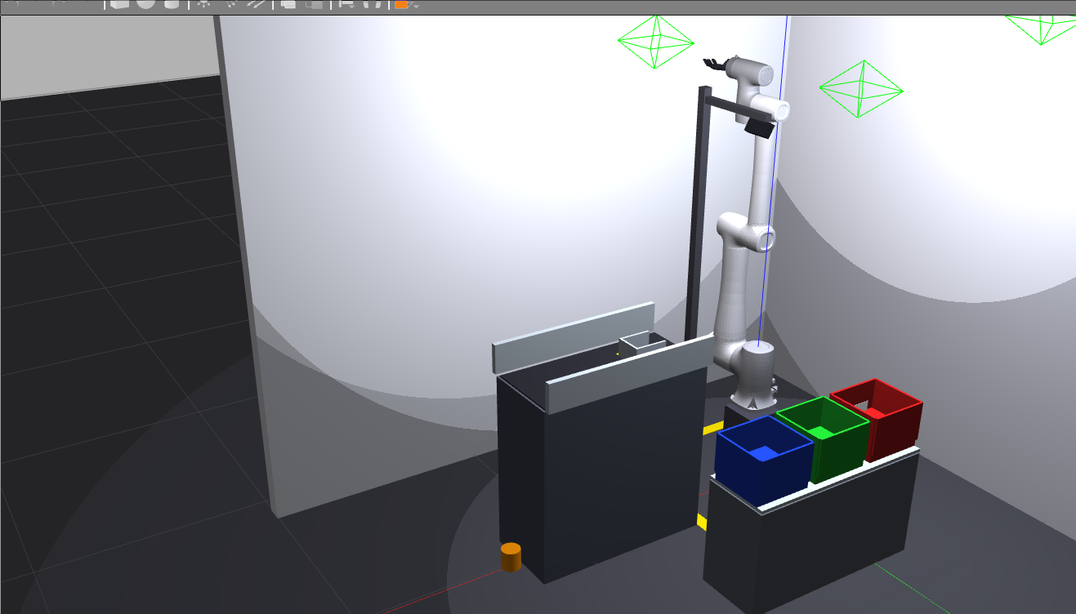
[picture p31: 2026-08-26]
images/conveyor_cell_gazebo_overview_early.png

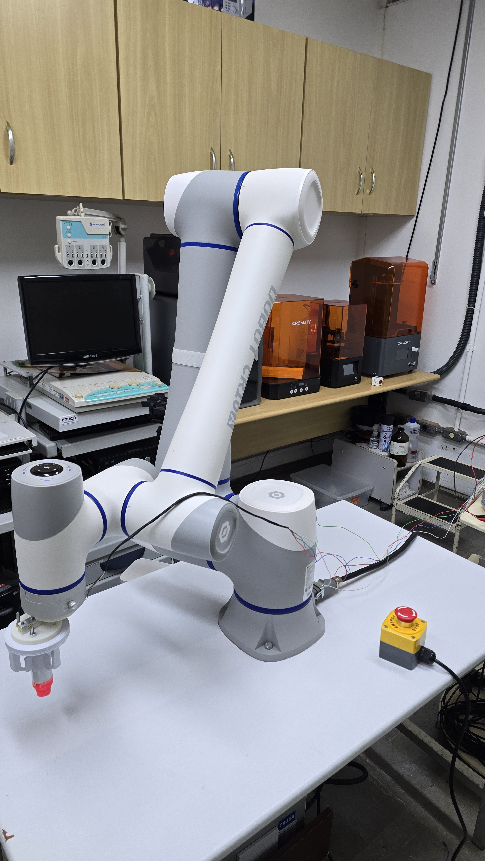
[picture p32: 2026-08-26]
images/physical_bench_cr10_overview.jpg

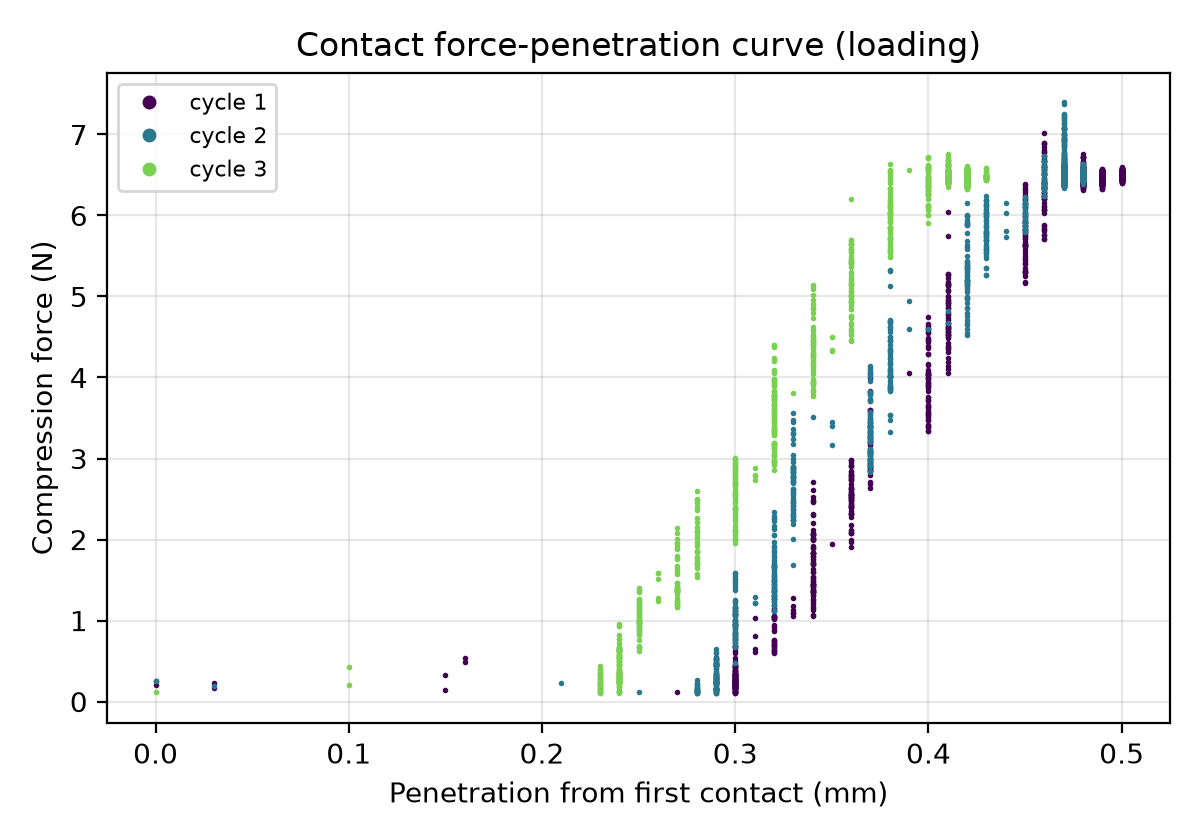
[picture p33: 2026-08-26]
images/force_penetration.png

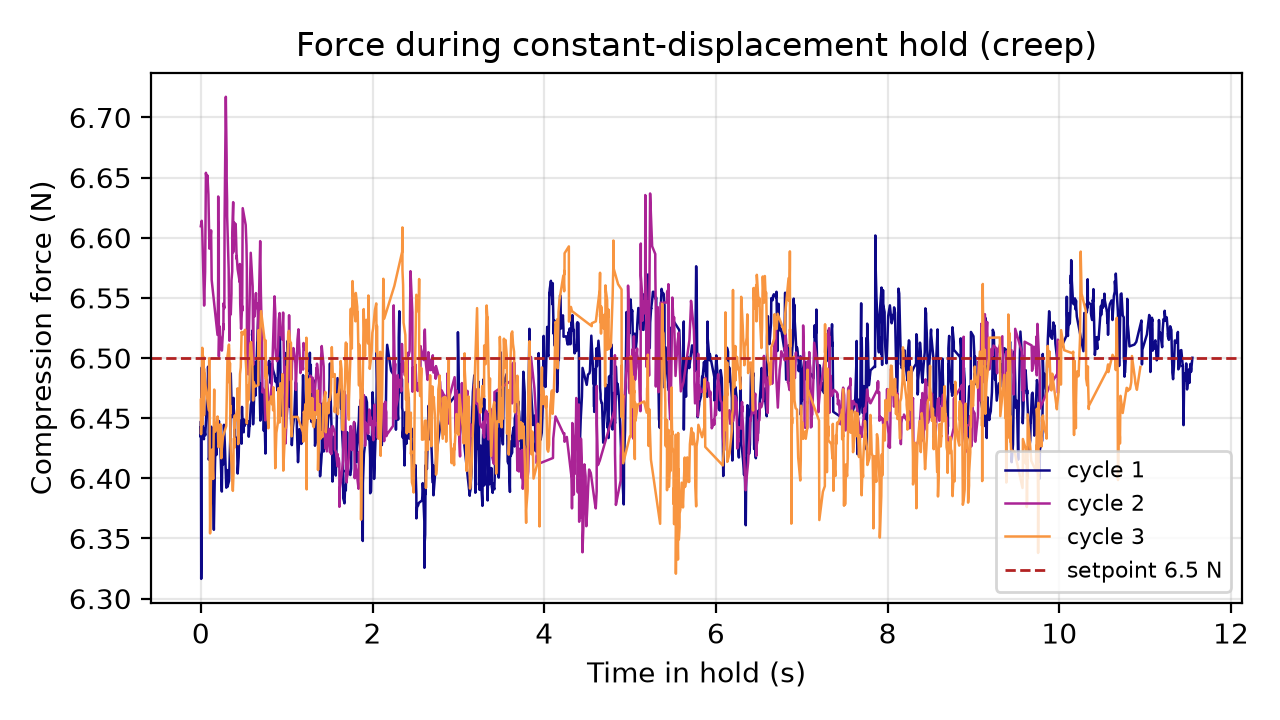
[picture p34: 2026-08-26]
images/creep_recovery.png

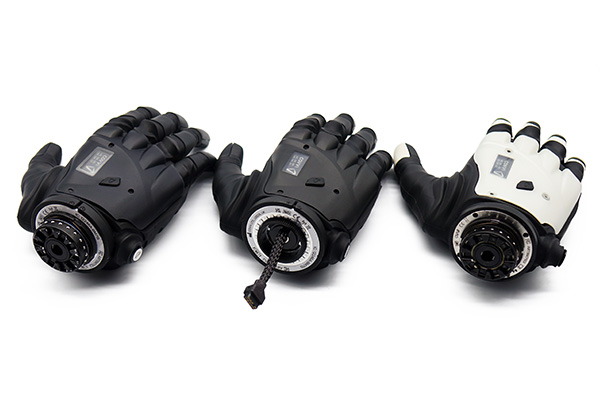
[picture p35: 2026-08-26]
images/covvi_hand_product_photo.jpg

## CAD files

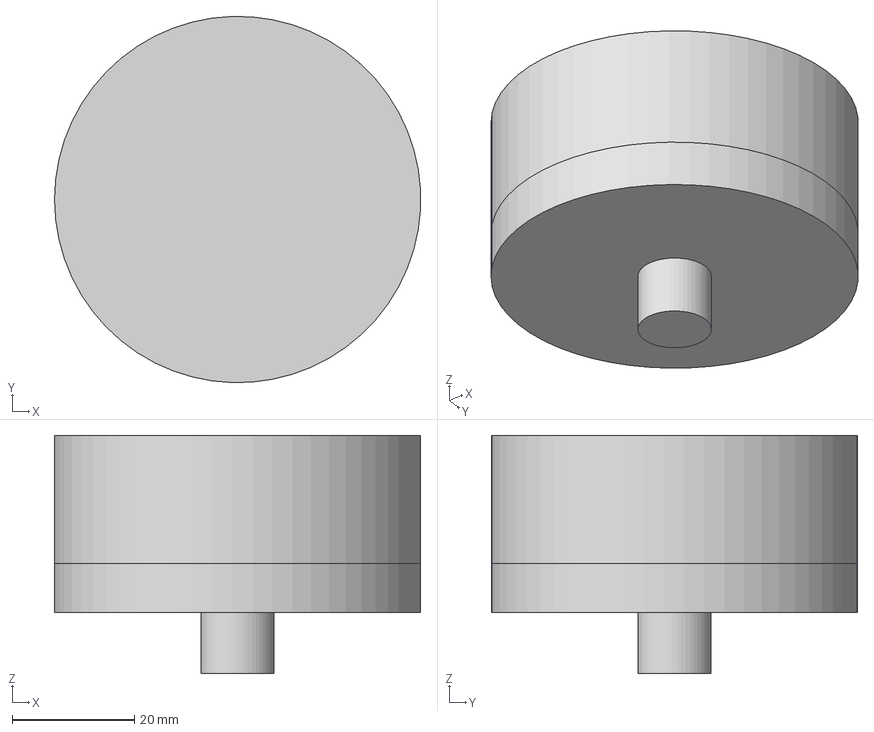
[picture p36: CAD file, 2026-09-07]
cad/step/montagem_molde_D.step
60.0 x 60.0 x 39.0 mm
ponteira_d_suporte
sensor_flex_inferior
sensor_camada_piezorresistiva
sensor_flex_superior

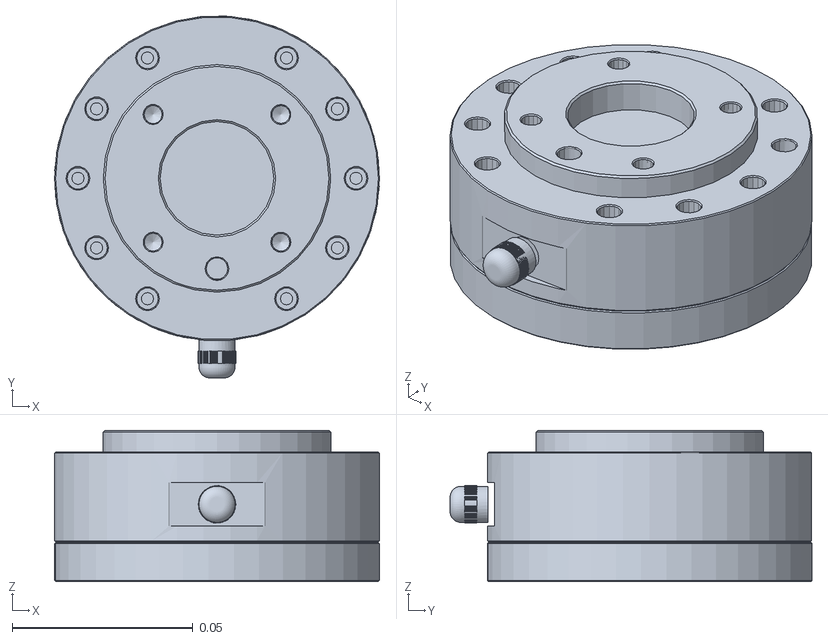
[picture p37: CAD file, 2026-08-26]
src/cra_description/meshes/cr10/Link6.STL
0.09 x 0.1 x 0.0419

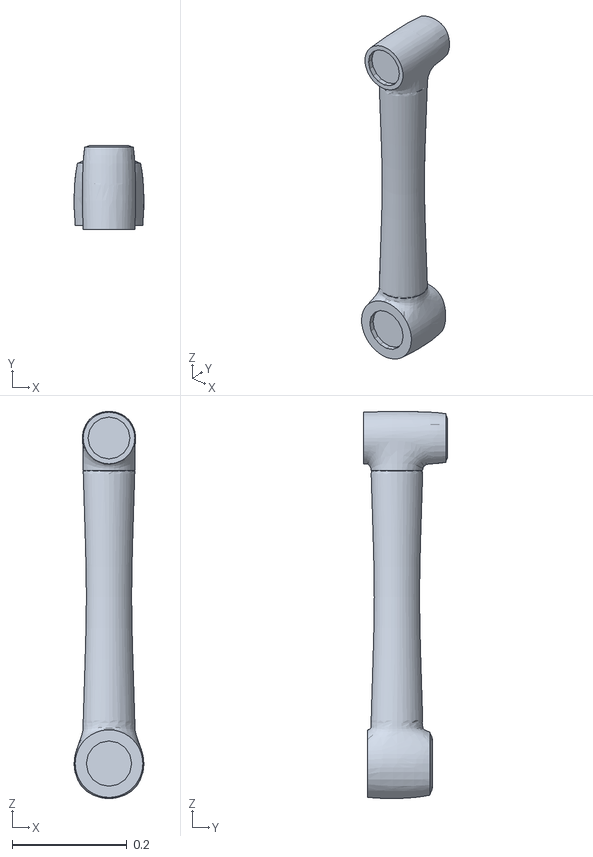
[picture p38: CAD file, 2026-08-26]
src/cra_description/meshes/cr10af/J3.STL
0.122 x 0.147 x 0.675

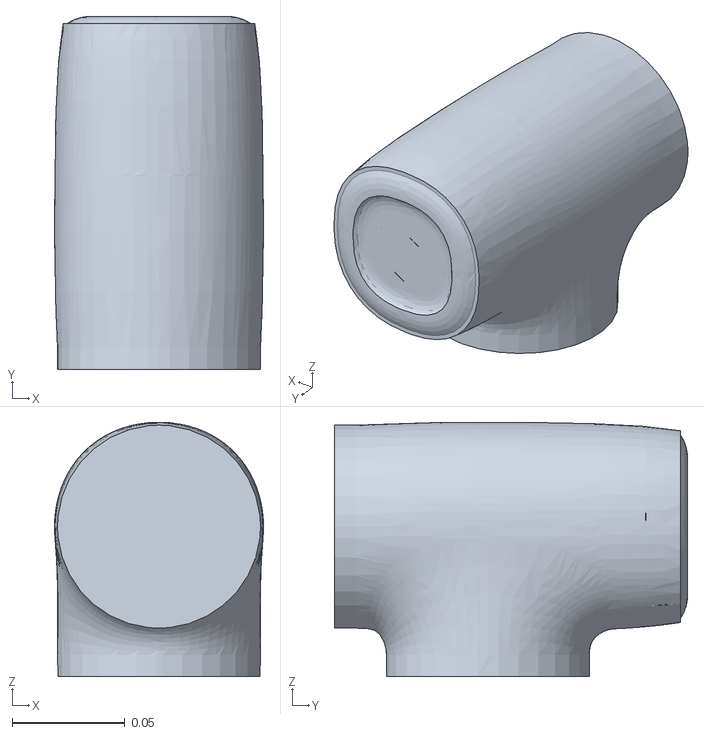
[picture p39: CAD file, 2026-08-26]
src/cra_description/meshes/cr12/J4.STL
0.0927 x 0.157 x 0.113

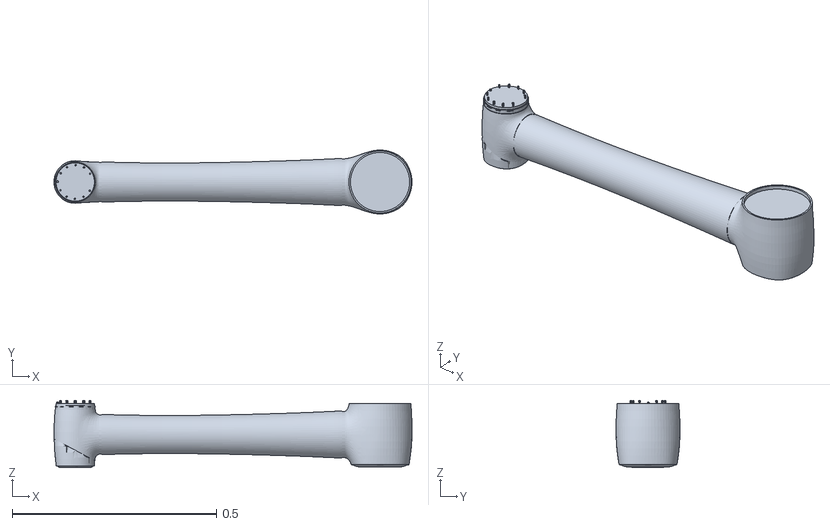
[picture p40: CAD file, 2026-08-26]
src/cra_description/meshes/cr20/Link3.STL
0.876 x 0.156 x 0.164

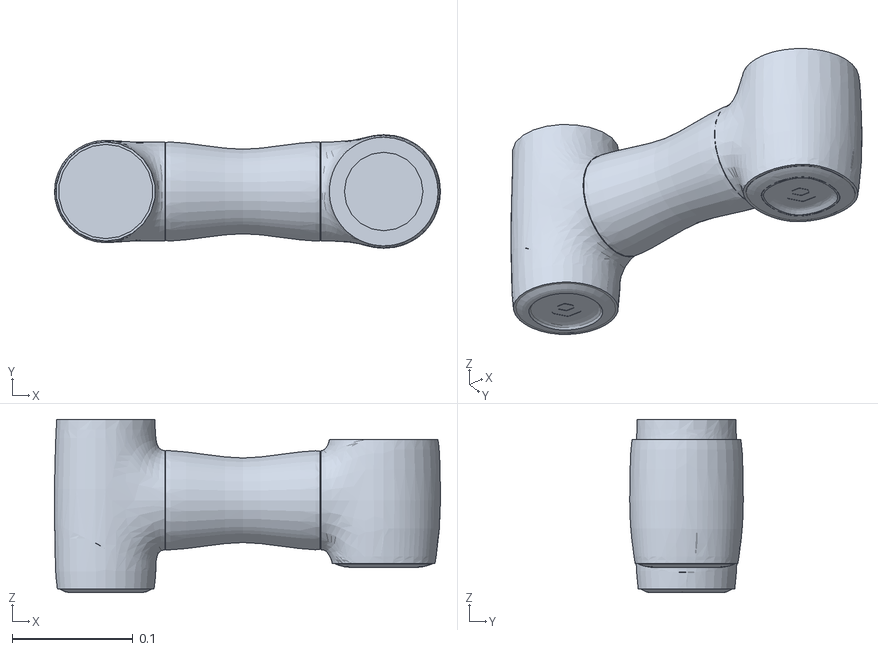
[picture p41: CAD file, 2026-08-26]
src/cra_description/meshes/cr3/J3.STL
0.319 x 0.094 x 0.144

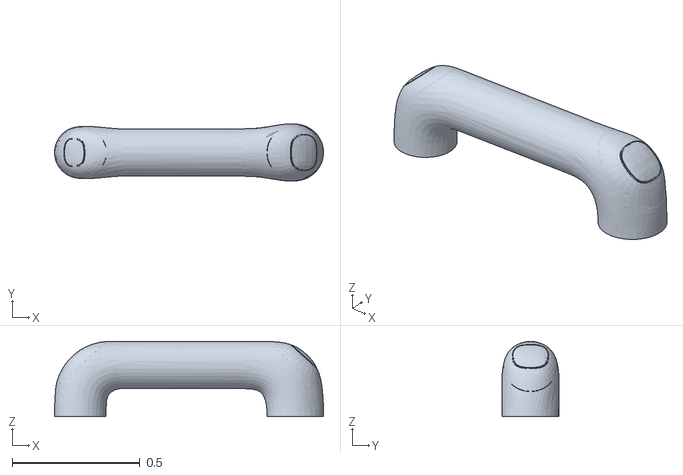
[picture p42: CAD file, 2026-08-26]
src/cra_description/meshes/cr30h/Link2.STL
1.05 x 0.224 x 0.295

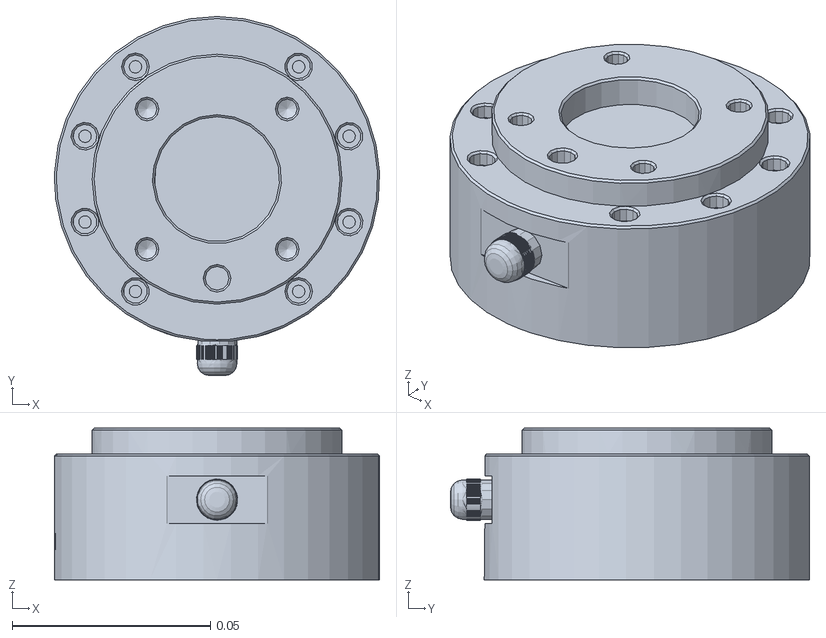
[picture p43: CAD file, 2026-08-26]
src/cra_description/meshes/cr5/J6.STL
0.082 x 0.0905 x 0.0382

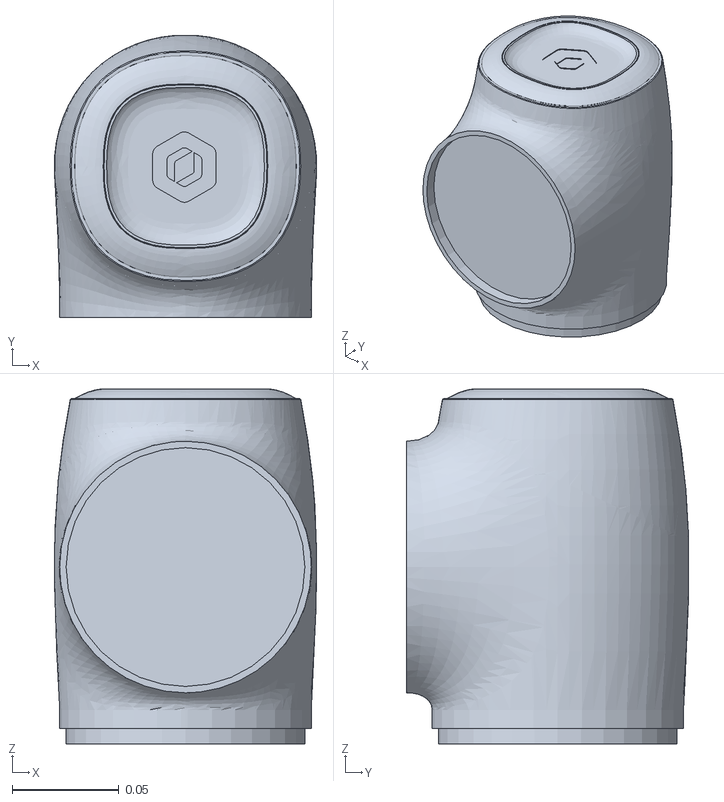
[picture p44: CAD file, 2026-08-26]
src/cra_description/meshes/cr7/J1.STL
0.123 x 0.132 x 0.167

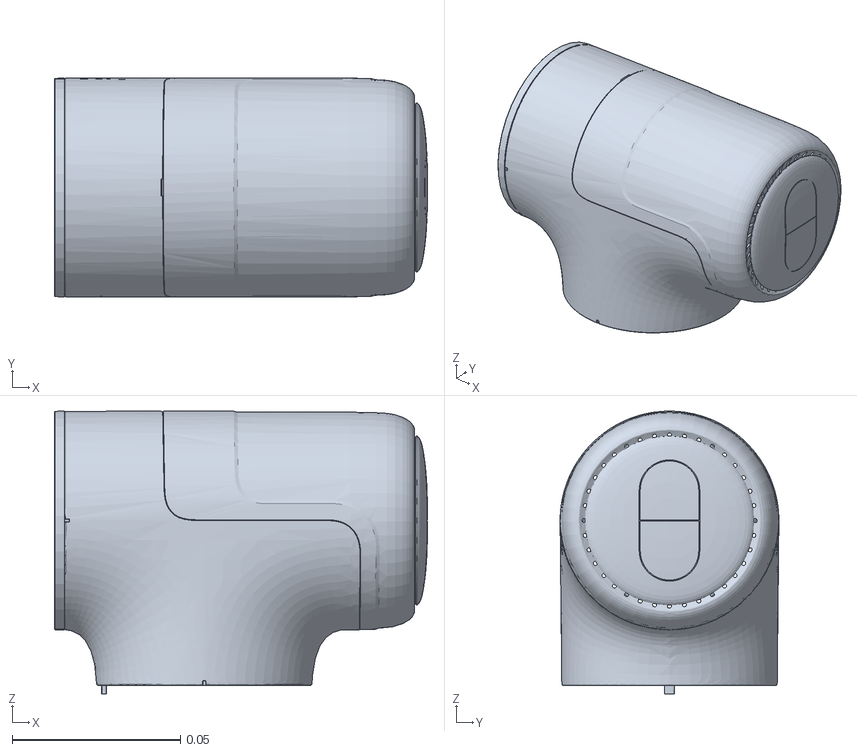
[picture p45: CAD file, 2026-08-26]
src/cra_description/meshes/me6/Link5.STL
0.111 x 0.065 x 0.084

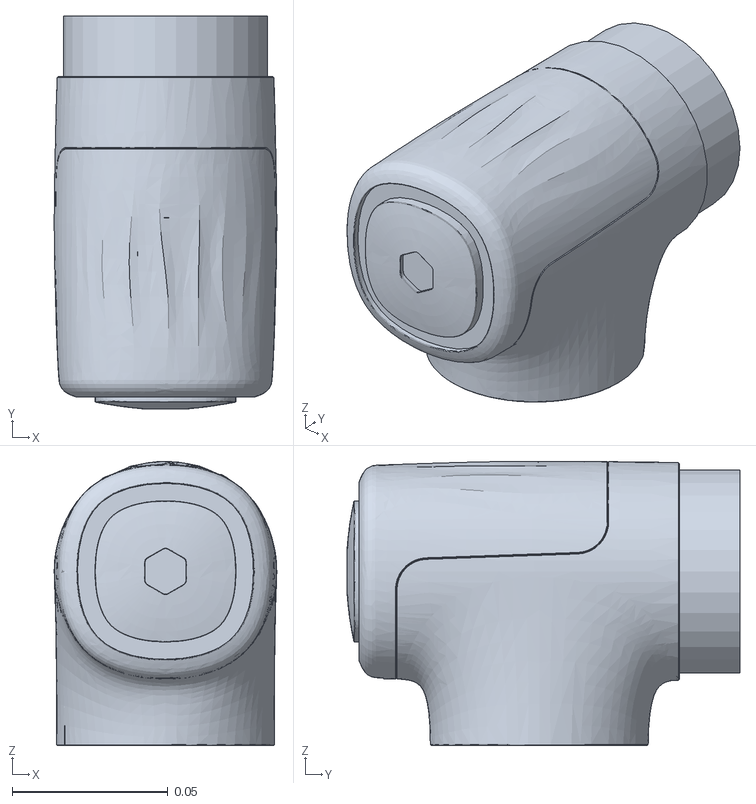
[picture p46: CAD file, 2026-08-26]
src/cra_description/meshes/nova2/Link5.STL
0.0715 x 0.126 x 0.0914

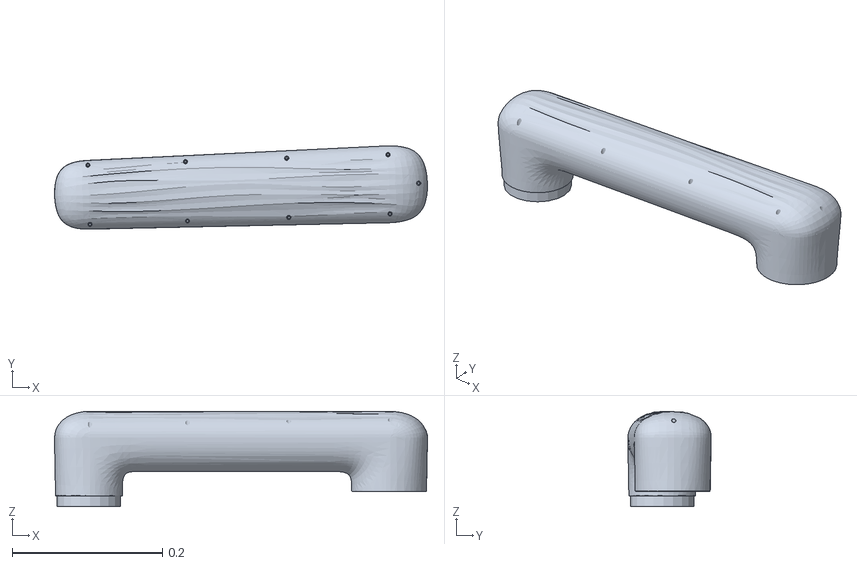
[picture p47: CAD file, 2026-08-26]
src/cra_description/meshes/nova5/Link2.STL
0.497 x 0.111 x 0.127

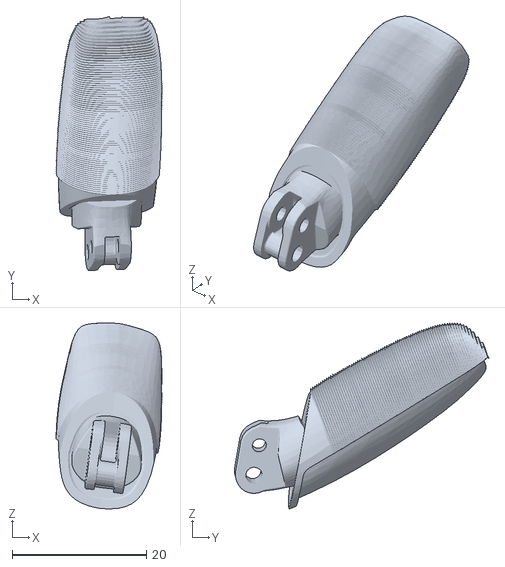
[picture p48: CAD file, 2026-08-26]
src/hand_pack/urdf/linear_meshes/right_ring_distal.STL
15.8 x 37.9 x 27.8

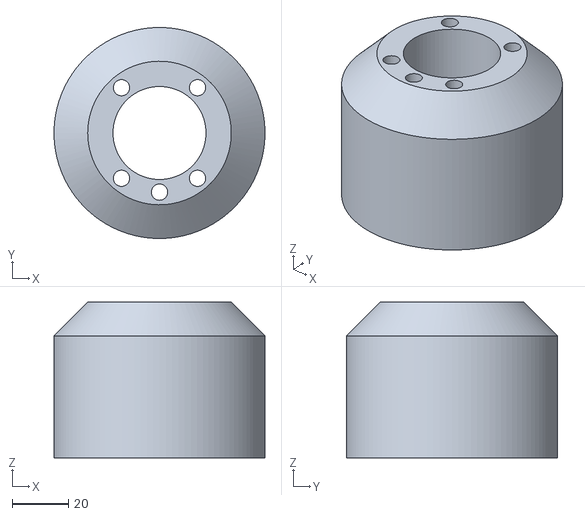
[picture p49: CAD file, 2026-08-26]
src/touch_pack/meshes/PecasProtese.stl
75.1 x 75.1 x 55.5

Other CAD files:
src/cra_description/meshes/cr16/Link6.STL
cad/step/tampa_D.step
src/cra_description/meshes/cr10/Link1.STL
src/cra_description/meshes/cr10af/base_link.STL
cad/step/FA7155 固定端法兰（需另购）.STEP
cad/step/FA7155D_20Nm.step
cad/step/MONTAGEM_COMPLETA.step
cad/step/MONTAGEM_FA7155_stack.step
cad/step/Placa STM32 - case.step
cad/step/Placa STM32 - tampa.step
cad/step/acoplador_celula_hotswap.step
cad/step/acoplador_robo.step
cad/step/acoplador_tool.step
cad/step/case_base.step
cad/step/case_tampa.step
cad/step/celula_carga_100kg.step
cad/step/molde_D.step
cad/step/molde_corpo_1.step
cad/step/molde_tampa.step
cad/step/placa_stm32_com_case.step
cad/step/placa_stm32_condicionamento_simplificada.step
cad/step/ponteira_A_quadrada_20x20.step
cad/step/ponteira_B_esferica_d10.step
cad/step/ponteira_C_pino_d3.step
cad/step/ponteira_D_sensor_5x5.step
cad/step/ponteira_E_quadrada_35.step
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

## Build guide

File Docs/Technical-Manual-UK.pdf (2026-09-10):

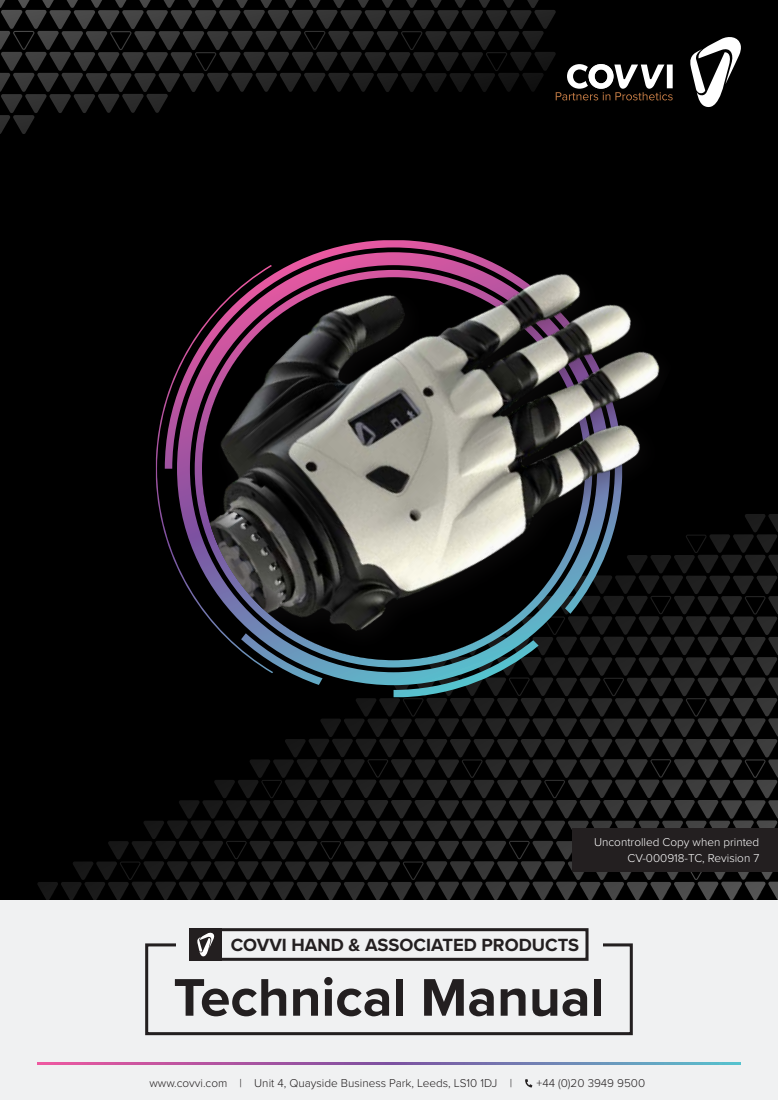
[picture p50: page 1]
www.covvi.com | Unit 4, Quayside Business Park, Leeds, LS10 1DJ |

Uncontrolled Copy when printed
CV-000918-TC, Revision 7

COVVI HAND & ASSOCIATED PRODUCTS
Technical Manual

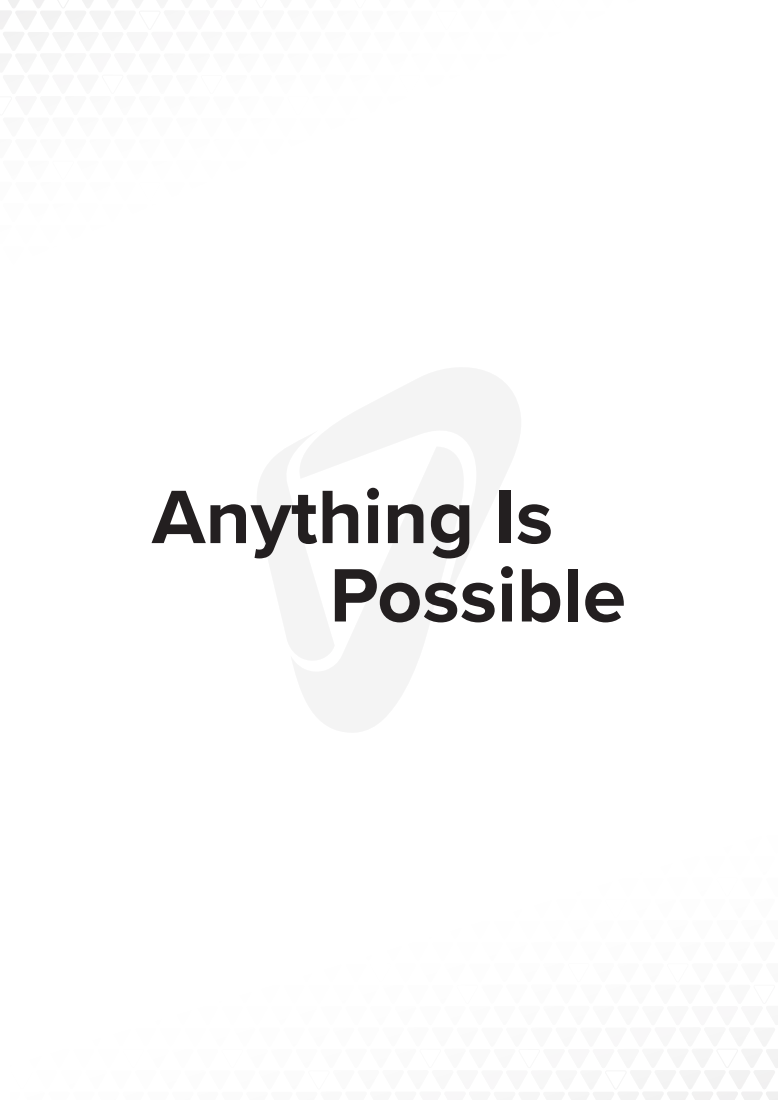
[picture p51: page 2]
Anything Is Possible

# Foreword

COVVI was founded in 2017 by a passionate and experienced team who wanted to continue to create leading multi-articulating device designs.
The human hand is amazing and the level of functionality which can be restored through prosthesis has historically been very low; but as engineers and designers we see this as a challenge to continuously improve our designs to meet the needs of users.
COVVI started with a blank sheet of paper and a mission to address some of the most prevalent deficiencies of current prosthetic hands. Fast forward to present day and we now have the best looking and most advanced multi-articulating hand on the market.

The COVVI Team

## Contents

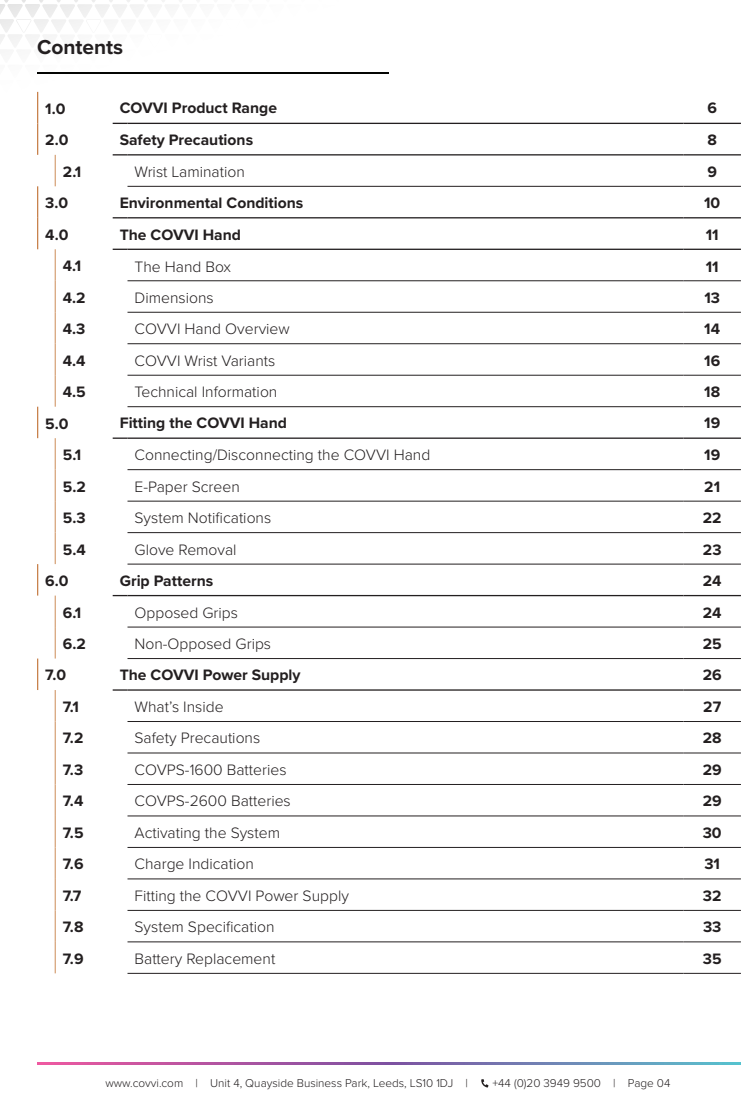
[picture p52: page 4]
www.covvi.com | Unit 4, Quayside Business Park, Leeds, LS10 1DJ |; +44 (0)20 3949 9500 | Page 04; COVVI Product Range; Safety Precautions; Wrist Lamination; Environmental Conditions; The COVVI Hand; The Hand Box; Dimensions; COVVI Hand Overview; COVVI Wrist Variants; Technical Information; Fitting the COVVI Hand; Connecting/Disconnecting the COVVI Hand; E-Paper Screen; System Notifications; Glove Removal; Grip Patterns; Opposed Grips; Non-Opposed Grips; The COVVI Power Supply; What’s Inside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

## Contents

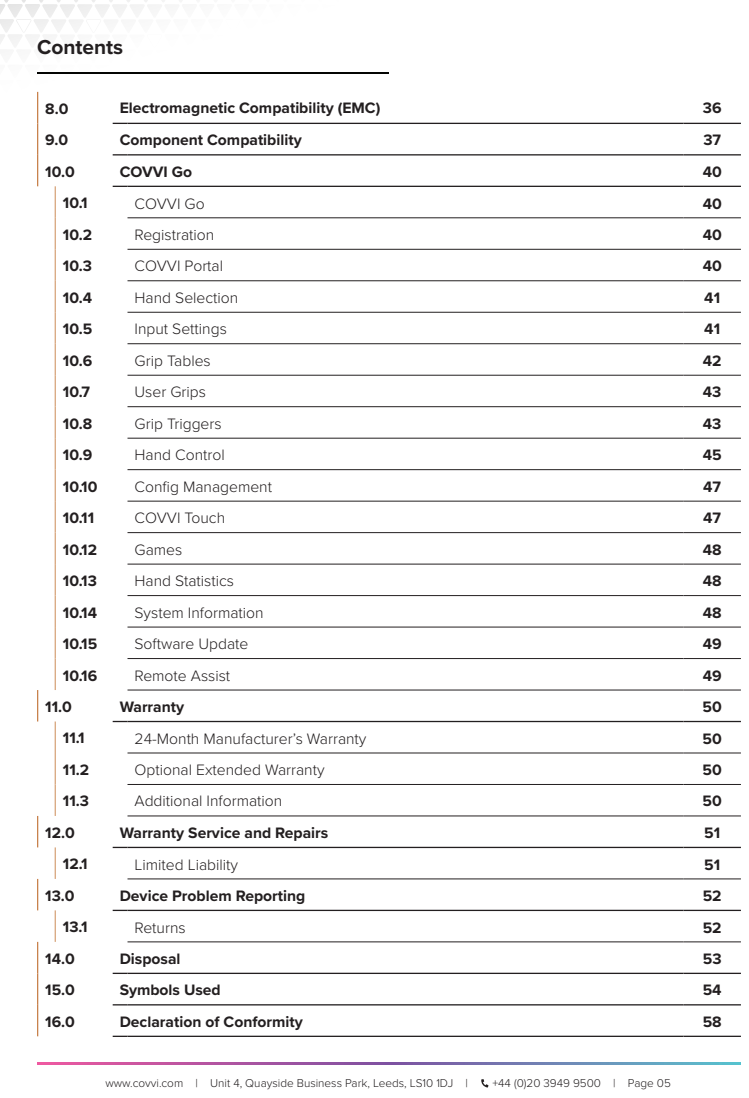
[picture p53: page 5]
www.covvi.com | Unit 4, Quayside Business Park, Leeds, LS10 1DJ |; +44 (0)20 3949 9500 | Page 05; Electromagnetic Compatibility (EMC); Component Compatibility; COVVI Go; Registration; COVVI Portal; Hand Selection; Input Settings; Grip Tables; User Grips; Grip Triggers; Hand Control; Config Management; COVVI Touch; Games; Hand Statistics; System Information; Software Update; Remote Assist; Warranty; 24-Month Manufacturer’s Warranty; Optional Extended Warranty; Additional Information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

www.covvi.com | Unit 4, Quayside Business Park, Leeds, LS10 1DJ | | +44 (0)20 3949 9500 | | Page 06

## 1.0 COVVI Product Range

COVPS-1600 | COVPS-2600

Coupling Piece

Lamination Ring

Wall Charger
(with adaptors)

Coaxial Core

The Hand Box
Contains one unit of the COVVI Hand, housed in protective material and shipped in a custom-sized box. The device is available in either left or right orientations, and in three sizes: small, medium and large. The Carbon Black, White and Titan Grey colour options are available for all sizes, while the Rose Gold is an option for small and medium hands only.
The COVVI Hand shown here is the Flex Wrist version, it is also available with either a Straight Wrist or Friction Wrist variant.

The Power Supply / Wall Charger Boxes
Spare Batteries and Wall Chargers can be ordered on their own, which will be shipped in their own custom boxes.
A full Battery Kit can also be ordered, which includes one power supply, a USB-C Wall Charger (with plug adaptors for different regions) and a USB-C Control Panel.
Please Note: Any orders for a Spare Battery or Battery Kit only contain either one of the 1600mAh or 2600mAh power supplies shown to the right. The Control Panel is also only included as a part of the Battery Kit.

The Wrist Assembly Kit Package
(Also known as the ‘COVVI Wrist Lamination Kit’)
When ordering a Coaxial Core, Coupling Piece or one size of a Lamination Ring (40mm, 45mm, 50mm), these components will be shipped in a bio-degradable plastic pouch.
A Wrist Assembly Kit is available that bundles all three of these items together, where they will be packaged and shipped together.
Please Note: Multiple items from different product ranges can be ordered together, and they will all be securely packaged into one of our custom shipping boxes.

Components for EQD (Flex and Straight Wrist Variants)

www.covvi.com | Unit 4, Quayside Business Park, Leeds, LS10 1DJ | | +44 (0)20 3949 9500 | | Page 07

## 1.0 COVVI Product Range

The Glove Kit
Replacement Glove Kits can be ordered that contain a new COVVI Glove, Dorsal Cover and Retention Ring. Covers available in Carbon Black, White, Titan Grey and Rose Gold (Rose Gold is only available in small and medium). Please check the ordered kit is suitable for the size, orientation and type of COVVI Hand used.
Glove Kit: Compatible with the COVVI Hand.
Glove Kit 2: Comes with two Retention Ring halves that are compatible with
| the COVVI Hand - Straight Wrist and COVVI Hand - Friction Wrist variants.

Please Note: Fixings cannot be used across Glove Kit versions.

COVVI Friction Wrist Switch Block
The Switch Block must be ordered alongside a COVVI Hand - Friction Wrist in order to connect the Hand to the auxiliary control and power components within the prosthesis socket.

COVVI Friction Wrist Lamination Ring
50mm Lamination Ring for the COVVI Hand - Friction Wrist.

COVVI Friction Wrist Installation Tool
An assistive tool that helps with the installation and removal of the COVVI Hand - Friction Wrist.

Components for Friction Wrist

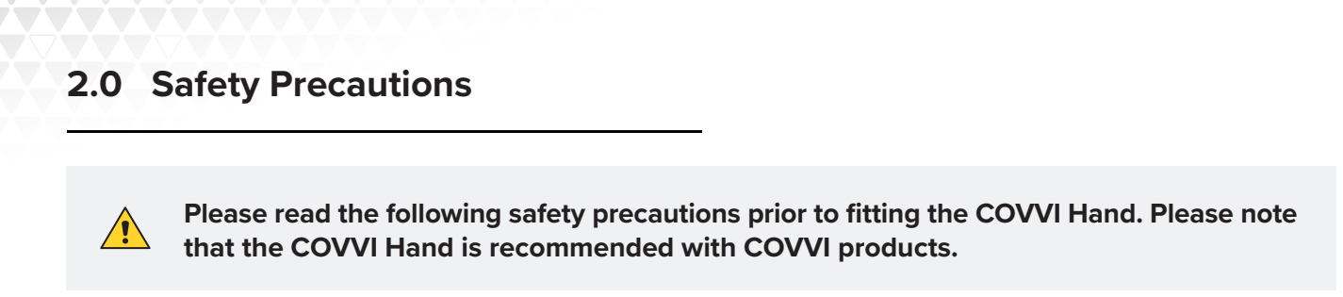
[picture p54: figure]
2.0 Safety Precautions

www.covvi.com | Unit 4, Quayside Business Park, Leeds, LS10 1DJ | | +44 (0)20 3949 9500 | | Page 08

In this Technical Manual, the term ‘COVVI Hand’ refers to all wrist variants. If any instructions, warnings, or information apply only to a specific wrist type, this will be clearly stated as applying to the COVVI Hand with Flex Wrist, Straight Wrist, or Friction Wrist.
The COVVI Hand should only be fitted by a Certified Prosthetist or Technician.
Certified Prosthetists and Technicians can remove the silicone glove from the hand and install a new silicone glove ONLY when training has been completed, and a certificate has been issued by a COVVI Representative.
NO other disassembly can be performed unless you have received specific training by COVVI and a certificate has been issued by a COVVI Representative.
COVVI Ltd. and COVVI USA INC have the right to void the warranty of all products that have any type of modification or damage caused by any unauthorised or untrained personnel.
- Do NOT use the COVVI Hand without the integrated silicone glove as it protects the hand from water ingress and other foreign bodies, which could damage the internal components and cause the hand to fail.
- The COVVI Hand has been tested and certified with an IP44 rating, classifying the degree of protection against solids and water of the hand to solid objects over 1mm in diameter and sprays and splashes from all directions. However, the wrist interface is not IP44 water or dust resistant.
- Do NOT submerge the COVVI Hand in water. Any damage caused by intentional submersion in water will not be covered under the warranty. If the glove is punctured, it will affect the IP44 rating of the hand.
- Do NOT attempt to use the COVVI Hand while the batteries are charging. When the batteries are charging, the power will automatically turn off. If for any reason the power does not turn off while charging, using the hand can be potentially unsafe.
- Do NOT use the COVVI Hand if a failure occurs, as it could cause damage to your patient or others.
- Do NOT use an additional glove with the COVVI Hand. Cosmetic gloves from other manufacturers restrict the movement of the hand, resulting in lower battery life, reduced grip strength and an increased internal temperature.
- The Essential Performance is to move the digits only when an input signal is applied. Should the fingers and/or thumb move without an input, the patient should stop using the COVVI Hand immediately and contact their clinician to get in touch with COVVI Customer Services.
This symbol is used in instances to warn about hazardous or dangerous materials and/or objects and will be used throughout this document.

Please read the following safety precautions prior to fitting the COVVI Hand. Please note that the COVVI Hand is recommended with COVVI products.

# CAUTION

PRECAUTIONS FOR HANDLING
ELECTROSTATIC SENSITIVE DEVICES.

www.covvi.com | Unit 4, Quayside Business Park, Leeds, LS10 1DJ | | +44 (0)20 3949 9500 | | Page 09
- We do not recommend the use of carbon fibre materials in a fabricated socket unless it is grounded to the carbon fibre lamination.
- This hand uses semiconductors that can be damaged by electrostatic discharge (ESD).
- Individuals who are exposed to hazardous environments that contain flammable liquid or gas should NOT operate the COVVI Hand when in those environments.
- Do NOT subject the COVVI Hand to intentional excessive impacts. Any damage caused by intentional harm or neglect will not be covered under the warranty.
- Do NOT expose the COVVI Hand to an open flame.
- Do NOT use the COVVI Hand to operate a firearm.
- Do NOT expose the COVVI Hand to chemicals such as solvents, acids, alkalis, corrosive substances, detergents, and similar chemicals, as this could damage the components in the hand. If the COVVI Hand needs cleaning, mild soap and a soft damp cloth should be used. Abrasive cleaners and cleaning cloths will scratch the covers.
- Before operating a vehicle with the COVVI Hand, local regulations should be checked, and the patient’s insurance company must be notified. We recommend that the prosthesis is fully charged. In the event of an accident occurring while operating a vehicle with a COVVI Hand or any other COVVI product, COVVI Ltd. and COVVI USA INC shall not be liable under any circumstances.
- The COVVI Hand is not suitable for extreme sports. These include, but are not limited to: base jumping, sky diving, downhill/endurance mountain biking, motocross, rock climbing, abseiling, bouldering and power lifting. Any sport that would involve the COVVI Hand getting wet must be avoided. These include, but are not limited to: diving, swimming, snorkelling, surfing, kayaking and canoeing.
- The COVVI Hand is NOT suitable to support body weight on crutches; we recommend that the hand is NOT used with crutches.
- Avoid remaining in the vicinity of visible strong magnetic or electrical interference, such as theft prevention systems.
- Maintain extra caution when handling sharp objects.
- Do NOT subject the hand to impact from sharp-edged or pointed objects.

COVVI Ltd. and COVVI USA INC have the right to void the warranty of all products that have any type of modification or damage caused by any unauthorised or untrained personnel.

## 2.0 Safety Precautions

### 2.1 Wrist Lamination

Ensure that the wrist is adequately laminated to the socket prior to use. Do not use the product if there are cracks in the lamination or if there is play between the socket and the Wrist Lamination Ring.

www.covvi.com | Unit 4, Quayside Business Park, Leeds, LS10 1DJ | +44 (0)20 3949 9500 | Page 10

The COVVI Hand is to be used exclusively for upper extremity device fittings. Based on the environmental conditions below, the patient should not use, transport, or store the hand outside of the boundaries listed below.

## 3.0 Environmental Conditions

Maximum Temperature | 104°F / 40°C
Minimum Temperature | -4°F / -20°C
Humidity | Maximum 80%, non-condensing
Pressure | 101.3kPa / 14.7psi

## 4.0 The COVVI Hand

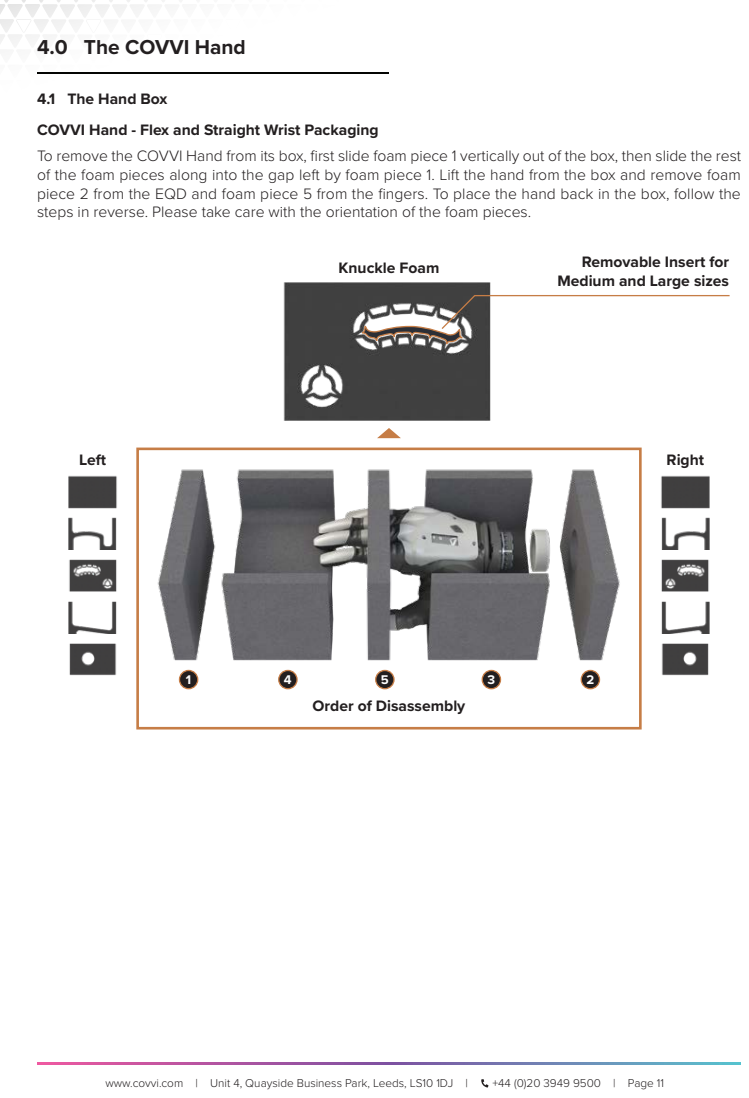
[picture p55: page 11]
www.covvi.com | Unit 4, Quayside Business Park, Leeds, LS10 1DJ |; | Page 11; Right; Knuckle Foam; Left

4.1 The Hand Box
COVVI Hand - Flex and Straight Wrist Packaging
To remove the COVVI Hand from its box, first slide foam piece 1 vertically out of the box, then slide the rest
of the foam pieces along into the gap left by foam piece 1. Lift the hand from the box and remove foam
piece 2 from the EQD and foam piece 5 from the fingers. To place the hand back in the box, follow the
steps in reverse. Please take care with the orientation of the foam pieces.

Removable Insert for
Medium and Large sizes

Order of Disassembly

## 4.0 The COVVI Hand

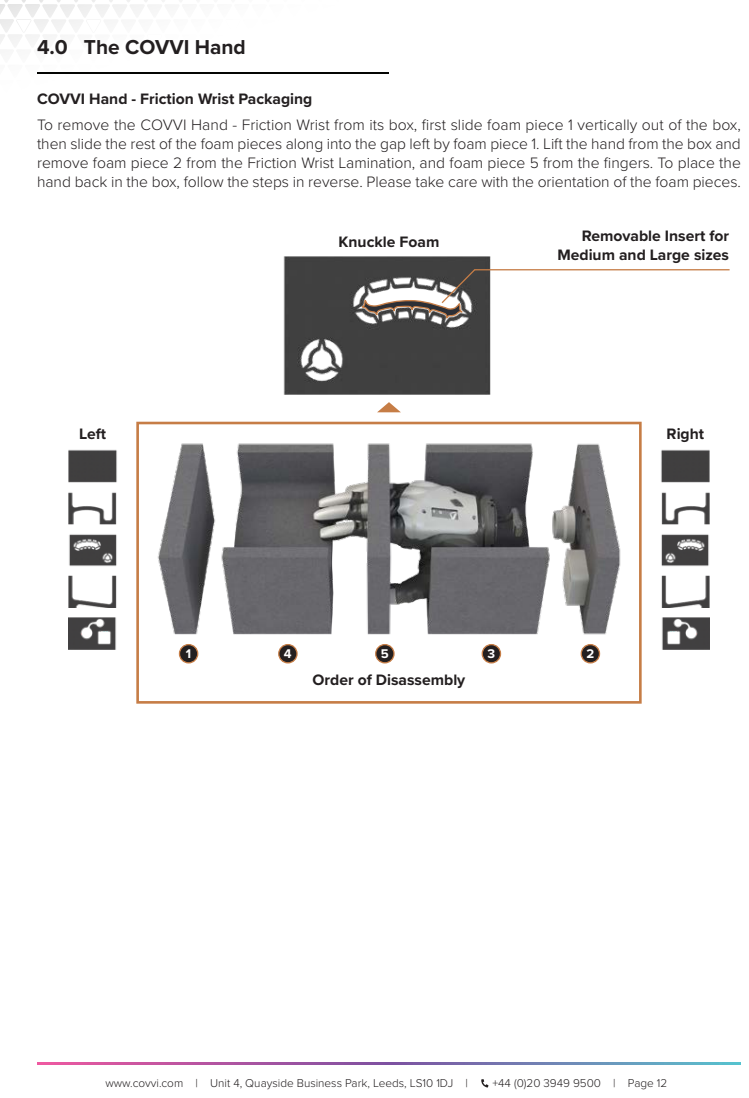
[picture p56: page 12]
www.covvi.com | Unit 4, Quayside Business Park, Leeds, LS10 1DJ |; | Page 12; Right; Knuckle Foam; Left

COVVI Hand - Friction Wrist Packaging
To remove the COVVI Hand - Friction Wrist from its box, first slide foam piece 1 vertically out of the box,
then slide the rest of the foam pieces along into the gap left by foam piece 1. Lift the hand from the box and
remove foam piece 2 from the Friction Wrist Lamination, and foam piece 5 from the fingers. To place the
hand back in the box, follow the steps in reverse. Please take care with the orientation of the foam pieces.

Removable Insert for
Medium and Large sizes

Order of Disassembly

www.covvi.com | Unit 4, Quayside Business Park, Leeds, LS10 1DJ | +44 (0)20 3949 9500 | Page 13

## 4.0 The COVVI Hand

### 4.2 Dimensions

Dimensions | Key | Small | Medium | Large
Inches | mm | Inches | mm | Inches | mm
Thumb Tip to Thumb Base | A | 4.3 | 110 | 4.5 | 114 | 4.9 | 124
Middle Finger to Base
(Flex Wrist) | B | 6.6 | 168 | 7.1 | 179 | 7.4 | 189

Middle Finger to Base
(Straight/Friction Wrist) | B | 6.4 | 163 | 6.9 | 174 | 7.2 | 184
Max. Chassis Width | C | 2.8 | 70 | 3 | 75 | 3.1 | 80
Palm Circumference | D | 7.5 | 190 | 7.7 | 195 | 7.9 | 200

Maximum Opening Width -
Tripod Grip | E | 3.4 | 86 | 3.6 | 92 | 3.9 | 100

## 4.0 The COVVI Hand

www.covvi.com | Unit 4, Quayside Business Park, Leeds, LS10 1DJ | | +44 (0)20 3949 9500 | | Page 14

Stainless Steel
Finger Pivot

High Impact
Polymer Chassis

E-Paper Screen

PEEK 450G EQD Female
Core and Ratchet Ring*

Stainless Steel
Knuckle

Stainless Steel
Wrist Plate

Cast Aluminium Digit Components

Stainless Steel
Finger Link

Stainless Steel
Finger Chassis

Machined Aluminium
Wrist Housing

Hardened Stainless
Steel Wrist Plate

ESD Pathway

Stainless Steel
Thumb Pivot Gears

### 4.3 COVVI Hand Overview

## 4.0 The COVVI Hand

www.covvi.com | Unit 4, Quayside Business Park, Leeds, LS10 1DJ | | +44 (0)20 3949 9500 | | Page 15

E-Paper Screen

Dorsal Button

Hardened 60A
Shore Fingertips

Touchscreen Compatibility
with the Index Finger

EQD - Electric Quick
Disconnect*

Friction Wrist with
Lamination Ring

Wrist Lock Button**

Optimised Fingertip
Geometry

FSRs in all the Fingertips

Thicker Palmar
Region

Flexible
Glove (IP44)

Flex Wrist***

*The EQD is not present if a Friction Wrist is installed
**The Wrist Locking Button is not operational if a Straight or Friction Wrist is installed ***The Flex Wrist is not present if a Straight or Friction Wrist is installed

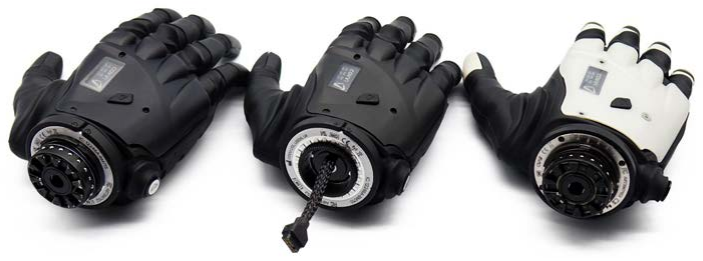
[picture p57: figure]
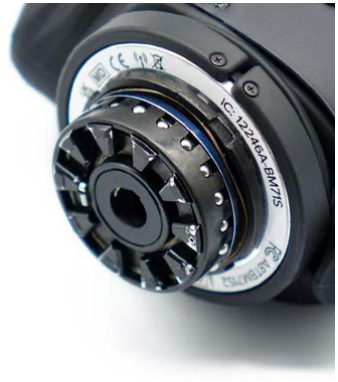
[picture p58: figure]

www.covvi.com | Unit 4, Quayside Business Park, Leeds, LS10 1DJ | | +44 (0)20 3949 9500 | | Page 16

## 4.0 The COVVI Hand

### 4.4 COVVI Wrist Variants

The COVVI Hand - Straight Wrist
The ‘Straight Wrist’ version of the COVVI Hand represents an industry standard, with its static wrist design.
At approximately 7% lighter than the COVVI Hand ‘Flex Wrist‘ version, installing this variant provides a solution that is both lighter and shorter, while still featuring an Electronic Quick Disconnect (EQD) connection. This model can easily be swapped with other prosthesis tools without clinical assistance.

The COVVI Wrist Suite is comprised of three distinct variants of the COVVI Hand, providing people with more varied types of limb differences access to this advanced multi-articulating hand.

The COVVI Hand - Flex Wrist
The original ‘Flex Wrist’ version of the COVVI Hand enables users to adjust their wrist angle for various tasks, offering 27° of flexion and extension that can be securely locked. This allows users to flex inwards to perform tasks like zipping up a jacket, as well as extending outward for activities like pushing carts.

www.covvi.com | Unit 4, Quayside Business Park, Leeds, LS10 1DJ | +44 (0)20 3949 9500 | Page 17

## 4.0 The COVVI Hand

The COVVI Hand - Friction Wrist
The ‘Friction Wrist’ version has been designed specifically for people with a longer residual limb. As the shortest and lightest variant of the COVVI Hand when installed on a prosthesis, its connection can be built directly into a user’s socket. This means that for users with longer limbs, the shorter wrist configuration provides an improved cosmetic appearance and positioning.
In addition to this, the Friction Wrist variant is just under 12% lighter compared to the COVVI Hand when a Flex Wrist is installed.

The COVVI Hand structural height is defined as the distance from the Thumb Tip to the Base of the EQD Lamination Ring or Friction Wrist Lamination Ring.
The first number in each measurement above is the distance from the Thumb Tip to the Base of the Hand. The second number is the distance from the Base of the Hand to the Base of the Lamination Ring. The overall structural height is the total of these two measurements.
Structural Height | Small Hand | Medium Hand | Large Hand
COVVI Hand - Flex Wrist | 122 + 25mm / 4.8 + 0.98 inches | 133 + 25mm / 5.2 + 0.98 inches | 136 + 25mm / 5.4 + 0.98 inches
| 4.6 + 0.98 inches | 128 + 25mm / 5.0 + 0.98 inches
COVVI Hand - Friction Wrist | 117 + 10mm / 4.6 + 0.4 inches | 128 + 10mm / 5.0 + 0.4 inches | 131 + 10mm / 5.2 + 0.4 inches
COVVI Hand - Straight Wrist | 117 + 25mm /

131 + 25mm /
5.2 + 0.98 inches

## 4.0 The COVVI Hand

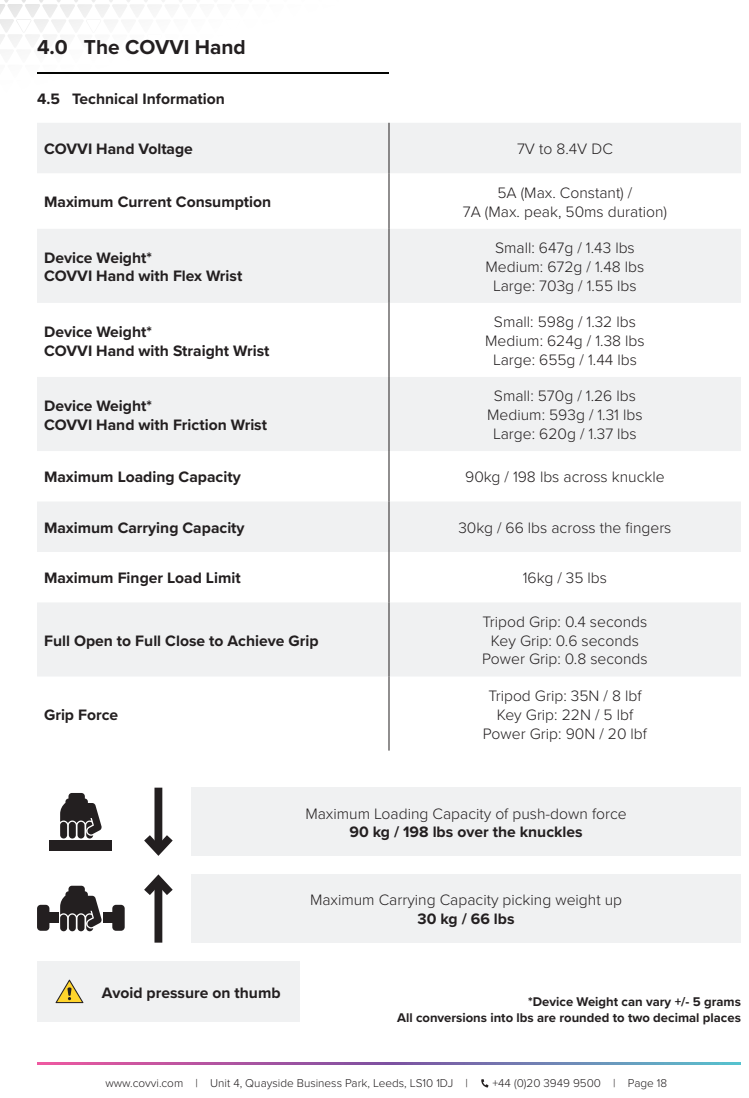
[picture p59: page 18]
www.covvi.com | Unit 4, Quayside Business Park, Leeds, LS10 1DJ |; +44 (0)20 3949 9500 | Page 18; 30 kg / 66 lbs; 4.5 Technical Information; COVVI Hand Voltage; Maximum Current Consumption; 5A (Max. Constant) /; Maximum Loading Capacity; 90kg / 198 lbs across knuckle; Maximum Carrying Capacity; 30kg / 66 lbs across the fingers; Maximum Finger Load Limit; 16kg / 35 lbs; Grip Force

7A (Max. peak, 50ms duration)
Small: 647g / 1.43 lbs
Medium: 672g / 1.48 lbs
Large: 703g / 1.55 lbs
Small: 598g / 1.32 lbs
Medium: 624g / 1.38 lbs
Large: 655g / 1.44 lbs
Small: 570g / 1.26 lbs
Medium: 593g / 1.31 lbs
Large: 620g / 1.37 lbs

Device Weight*
COVVI Hand with Flex Wrist

COVVI Hand with Straight Wrist

COVVI Hand with Friction Wrist

Tripod Grip: 0.4 seconds
Key Grip: 0.6 seconds
Power Grip: 0.8 seconds
Tripod Grip: 35N / 8 lbf
Key Grip: 22N / 5 lbf
Power Grip: 90N / 20 lbf

Full Open to Full Close to Achieve Grip

Maximum Loading Capacity of push-down force
90 kg / 198 lbs over the knuckles

Maximum Carrying Capacity picking weight up

Avoid pressure on thumb

*Device Weight can vary +/- 5 grams

All conversions into lbs are rounded to two decimal places

www.covvi.com | Unit 4, Quayside Business Park, Leeds, LS10 1DJ | | +44 (0)20 3949 9500 | | Page 19

These instructions only apply to the COVVI Hand if a Flex or Straight Wrist is installed
- Make sure the Power Supply is OFF before connecting/disconnecting the hand to and from the prosthesis.
- Only turn the power on once the hand is properly connected to the prosthesis.
Please see the image below for instructions on how to connect the hand to the socket.

If the ball bearings are locked out radially, the hand will not plug in. Please Note: The Wrist Plate marking may vary between variants.

Remove protective cap

Ensure no debris is inside the EQD core before connecting the hand to the socket.

## 5.0 Fitting the COVVI Hand

### 5.1 Connecting/Disconnecting the COVVI Hand

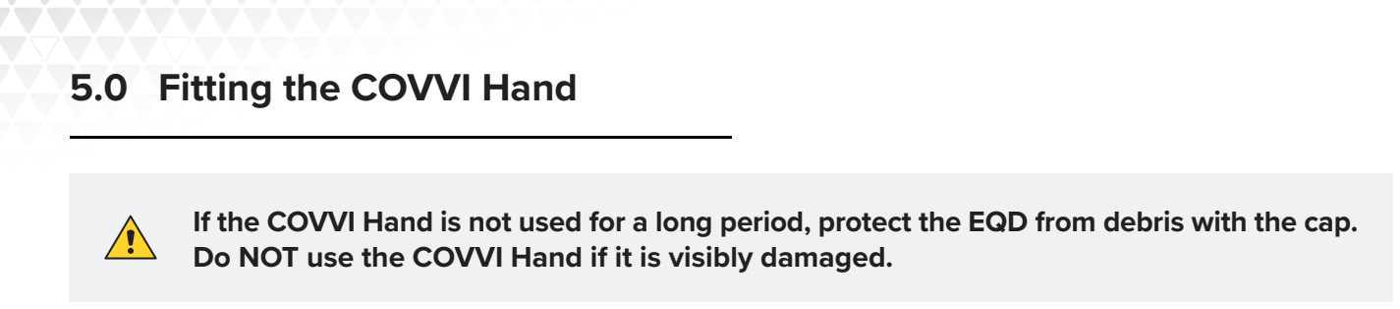
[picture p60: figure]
5.0 Fitting the COVVI Hand

www.covvi.com | Unit 4, Quayside Business Park, Leeds, LS10 1DJ | | +44 (0)20 3949 9500 | | Page 20

If the COVVI Hand is not used for a long period, protect the EQD from debris with the cap. Do NOT use the COVVI Hand if it is visibly damaged.

- To connect the hand to the socket, push and twist the EQD into the wrist on the socket.
- To check that the hand is properly connected, twist it in the socket and pull lightly. If it wobbles, it isn’t properly connected.
- To disconnect the hand from the socket, twist and pull it.
- If the hand is not properly connected, you may experience BLE connectivity issues or App connectivity issues.

For fitment and removal of the COVVI Hand - Friction Wrist, please refer to the COVVI Hand - Friction Wrist Lamination and Fitment Guide: https://www.covvi.com/wp-content/uploads/documents/Friction-Wrist-Lamination-and-Fitment-Guide.pdf

www.covvi.com | Unit 4, Quayside Business Park, Leeds, LS10 1DJ | | +44 (0)20 3949 9500 | | Page 21

Current Grip

COVVI Touch

It will then display the following:

FW: The high-level Firmware. The image shows Version 6 followed by the date it was created.

GW: The low-level Gateware. The image shows Version 6 followed by the date it was created.

The COVVI Hand has an E-Paper screen which shows important hand information. It requires no power to display and little power to change the display, so it doesn’t drain the battery life.
When you turn the hand on, the E-Paper screen will display the following:

It always shows the current grip, table and battery life. The Bluetooth icon will be displayed for 60 seconds, and then it will disappear as Bluetooth will automatically turn off; this is a battery saving feature. If you connect to the hand through the App, the Bluetooth icon will remain on the E-Paper screen until you close the App and disconnect from the hand.

Grip Table

Estimated Battery Life

Bluetooth is enabled
for 60 seconds

## 5.0 Fitting the COVVI Hand

### 5.2 E-Paper Screen

www.covvi.com | Unit 4, Quayside Business Park, Leeds, LS10 1DJ | | +44 (0)20 3949 9500 | | Page 22

When Auto Grip is enabled, if the hand senses an object is slipping it reapplies a small continuous force to grasp the object. Auto Grip works in Power Grip, Tripod Grip, Precision Open and Precision Closed. Auto Relax moves the hand to a relaxed position after a period of inactivity. A user input signal will cause the hand to revert to its previous grip, and the icon will be removed.
A short press to the dorsal button (under two seconds) puts the hand into Standby Mode, where user inputs from the electrodes have no effect on the hand. Pressing the dorsal button again will exit Standby Mode, and the icon will be removed.
The CAN bus icon is displayed whenever the hand is connected to a CAN-enabled device, such as the COAPT Gen2 system.
Please Note: This icon is only displayed once Bluetooth has turned off (the two icons share the same location on the display). The warning icon shows that the hand has detected a fault. The screen will also display text to identify what the fault is, for example, 1 of 1 Fault Thumb Sensor.

Fault detected

Standby Mode is activated | Connected to CAN bus

Auto Relax is enabled

| Auto Grip is enabled

## 5.0 Fitting the COVVI Hand

### 5.3 System Notifications

www.covvi.com | Unit 4, Quayside Business Park, Leeds, LS10 1DJ | | +44 (0)20 3949 9500 | | Page 23

When the COVVI Hand is too hot, outside of its normal operating temperature (see section 3.0), the following warning message and icon will appear. If this message appears, please disconnect the hand and allow it to cool down.

When the COVVI Hand is too humid, outside of its normal operating humidity (see section 3.0), the following warning message and icon will appear. If this message appears, please disconnect the hand and allow it to dry in a warm, dry environment.

Any function that refreshes the screen, for example, a grip change, will change the message displayed, but the warning icon will remain visible.
If the warning icons and messages do not disappear, please get in contact with COVVI Customer Services.

The following notifications will appear when you select to update the firmware in COVVI Go. The update downloads from the App to the hand, and

## 5.0 Fitting the COVVI Hand

For the removal and fitting of the standard COVVI Glove, refer to the COVVI Glove Replacement Guide in the User Guides section of the COVVI website: www.covvi.com/user-guides
Please refer to the standard Glove Fitment video for the COVVI Hand with the Flex Wrist, and refer to the Retention Ring Fitment video if your COVVI Hand is fitted with either the Straight or Friction Wrist. Glove fitment between hand variants is the same; however, the glove retention differs between models.

### 5.4 Glove Removal

www.covvi.com | Unit 4, Quayside Business Park, Leeds, LS10 1DJ | | +44 (0)20 3949 9500 | | Page 24

## 6.0 Grip Patterns

### 6.1 Opposed Grips

Tripod Grip

Rock Grip

Glove Grip

Power Grip

Trigger Grip

Precision
Closed Grip

You can find more opposed grips in the User Grips section of the App.

Precision
Open Grip

www.covvi.com | Unit 4, Quayside Business Park, Leeds, LS10 1DJ | | +44 (0)20 3949 9500 | | Page 25

Key/Card Grip

## 6.0 Grip Patterns

### 6.2 Non-Opposed Grips

Column Grip

Phone Grip

Finger Point Grip | Tap Grip | Relaxed Grip

Mouse Grip

You can find more non-opposed grips in the User Grips section of the App.

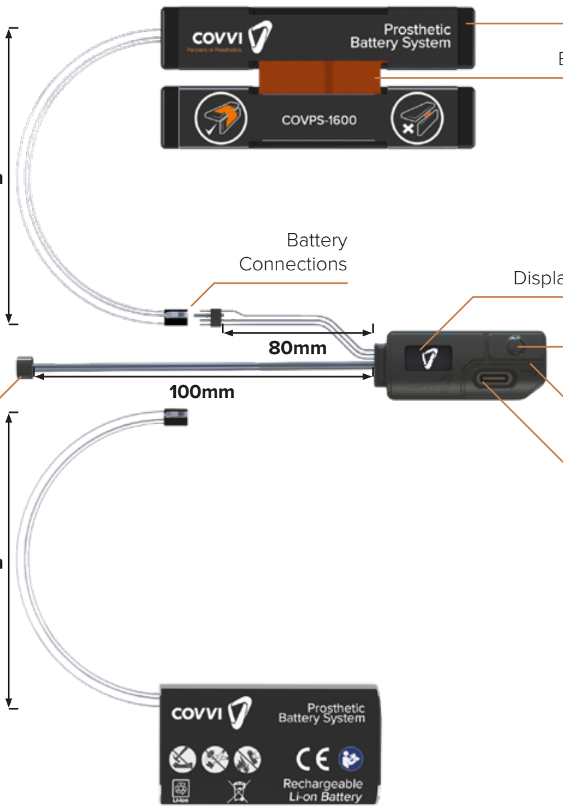
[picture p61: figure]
Battery Connections

www.covvi.com | Unit 4, Quayside Business Park, Leeds, LS10 1DJ | +44 (0)20 3949 9500 | Page 26

COVPS-2600
Option

2-pin Output
Power Connector
to EQD

Battery Cell

Battery Web

Display Screen

Power Button

Control
Panel

USB-C
Connector

COVPS-1600
Option

There are two Power Supply systems available: COVPS-2600 cylindrical cells with a system weight of 107 grams ideal for users with a short residual limb, and COVPS-1600 prismatic flat cells with a system weight of 74 grams and a web connecting the cells. This web allows the batteries to be folded, without bending the cells, to follow the contours of the inside of the prosthesis socket. This system is ideal for users with a long residual limb.
Both Power Supplies come with a Control Panel, which weighs an additional 18 grams. It has USB-C charging, the COVPS-1600 Power Supply takes under three hours to charge and the COVPS-2600 Power Supply takes roughly four hours to charge.

*The Power Supply is optimised for right handed socket installation. For left-handed sockets, the wire must be routed under the Control Panel, leaving 56mm of free wire.

## 7.0 The COVVI Power Supply

70mm

70mm

## 7.0 The COVVI Power Supply

www.covvi.com | Unit 4, Quayside Business Park, Leeds, LS10 1DJ | | +44 (0)20 3949 9500 | | Page 27

1 Battery

Silicone Adhesive

1 Battery Dummy

Velcro
Control Panel

Cutting Template
(Located in the COVPS Box)

### 7.1 What’s Inside

*COVPS-1600 Shown

AU | EU

USB-C Wall Charger

UK | US

Only use with COVVI Batteries

www.covvi.com | Unit 4, Quayside Business Park, Leeds, LS10 1DJ | | +44 (0)20 3949 9500 | | Page 28

### 7.2 Safety Precautions

## 7.0 The COVVI Power Supply

This product uses semiconductors that can be damaged by electrostatic discharge (ESD).

# CAUTION

PRECAUTIONS FOR HANDLING
ELECTROSTATIC SENSITIVE DEVICES.

Please read the following safety precautions prior to fitting the COVVI Power Supply.
- The Power Supply should only be fitted by a Certified Prosthetist or Technician.
- This product is not designed to be disassembled or serviced. COVVI Ltd. and COVVI USA INC have the right to void the warranty of all products that have any type of modification or damage caused by any unauthorised or untrained personnel. Any damage caused by intentional harm or neglect will not be covered under the warranty.
- Please make sure the Power Supply is OFF before connecting/disconnecting the prosthesis device, as this will avoid any unpredictable spikes in the electric current from the batteries.
- Do NOT attempt to use the prosthesis device while the batteries are charging. When the batteries are charging, the power will automatically turn off. If, for any reason, the power does not turn off while charging, using the prosthesis device can be potentially unsafe.
- Do NOT use the Power Supply if there is any visible sign of damage to the Power Supply charger, Power Plug and/or Cables.
- Do NOT expose the Power Supply to an open flame or submerge it in water. This could damage the screen and affect the battery’s ability to hold a charge.
- Do NOT use any solvents or abrasives to clean the Control Panel, as this might damage the paint finish, the clarity of the screen or the integrity of the silicone moulding.
- Do NOT fit the batteries into a small, enclosed space. The batteries are designed to inflate when they fail. Stopping this inflation may cause the generation of excessive heat, injury, or death.
- Individuals who are exposed to hazardous environments that contain flammable liquid or gas should NOT use the COVVI Power Supply when in those environments.
- Ensure access to the Wall Plug to enable easy isolation if required.
Please Note: We recommend you only use the COVVI USB-C Charger to charge the COVVI Power Supply.

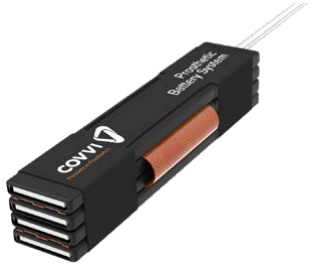
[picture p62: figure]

www.covvi.com | Unit 4, Quayside Business Park, Leeds, LS10 1DJ | | +44 (0)20 3949 9500 | | Page 29

The COVPS-1600 Battery is made up of four prismatic cells that can be bent either way along the brown connecting web.

The COVPS-2600 Battery is made up of two cylindrical cells.

### 7.3 COVPS-1600 Batteries

### 7.4 COVPS-2600 Batteries

## 7.0 The COVVI Power Supply

www.covvi.com | Unit 4, Quayside Business Park, Leeds, LS10 1DJ | | +44 (0)20 3949 9500 | | Page 30

Firmware

Press and hold the Power Button on the Control Panel for two seconds to turn the Power Supply on. The screen will display COVVI for two seconds and then the current charge level for five seconds. The system is now providing power to the hand. To turn the Power Supply off, press and hold the Power Button for two seconds.

Charge Level

To reduce power consumption, the screen is blank. To see the charge level, press the Power Button.

Press to show for

### 5 seconds

### 7.5 Activating the System

## 7.0 The COVVI Power Supply

www.covvi.com | Unit 4, Quayside Business Park, Leeds, LS10 1DJ | | +44 (0)20 3949 9500 | | Page 31

### 10 blocks equals 100%

### 7 blocks greater than or equal to 70%

### 8 blocks greater than or equal to 80%

### 9 blocks greater than or equal to 90%

### 6 blocks greater than or equal to 60%

### 3 blocks greater than or equal to 30%

### 4 blocks greater than or equal to 40%

### 5 blocks greater than or equal to 50%

### 7.6 Charge Indication

## 7.0 The COVVI Power Supply

### 1 block greater than or equal to 10%

### 2 blocks greater than or equal to 20%

No blocks less than 10%

When the system is charging, it will cycle through these screens

If there is a fault with the Power Supply, the OLED screen on the Control Panel will show the following warning icon. Please turn off the Power Supply and contact COVVI Customer Services.

7.51V 23°C

www.covvi.com | Unit 4, Quayside Business Park, Leeds, LS10 1DJ | | +44 (0)20 3949 9500 | | Page 32

The Control Panel should only be fitted by a Certified Prosthetist or Technician.
The information below is to be used as a guide; individual prostheses will differ from patient to patient. We recommend that the Control Panel is placed on the upper side of the prosthesis socket, away from any area which may be loadbearing when carrying heavy items. Lamination dummies are provided if recesses are required in the outer socket wall.

### Control Panel Aperture

Apply the cutting template to the top side of the prosthesis socket.

Carefully cut along the red outline with a cutting disc.
File down any sharp edges.

Remove the cutting template and apply a small bead of silicone adhesive to the edge of the aperture.

Insert the wires through the aperture before gently pressing the Control Panel into place.

The batteries can either be connected to the Control Panel prior to being fitted to the limb or after it is fitted if there is sufficient access space.
To ensure correct function, it is important to inspect the Control Panel carefully and ensure that the USB-C port is free of debris. If any debris is discovered, please carefully remove it with a thin, non-metallic object to ensure the port is not damaged.
If the Control Panel needs cleaning, mild soap and a soft, damp cloth should be used. Abrasive cleaners and cleaning cloths will scratch the covers.

### 7.7 Fitting the COVVI Power Supply

## 7.0 The COVVI Power Supply

## 7.0 The COVVI Power Supply

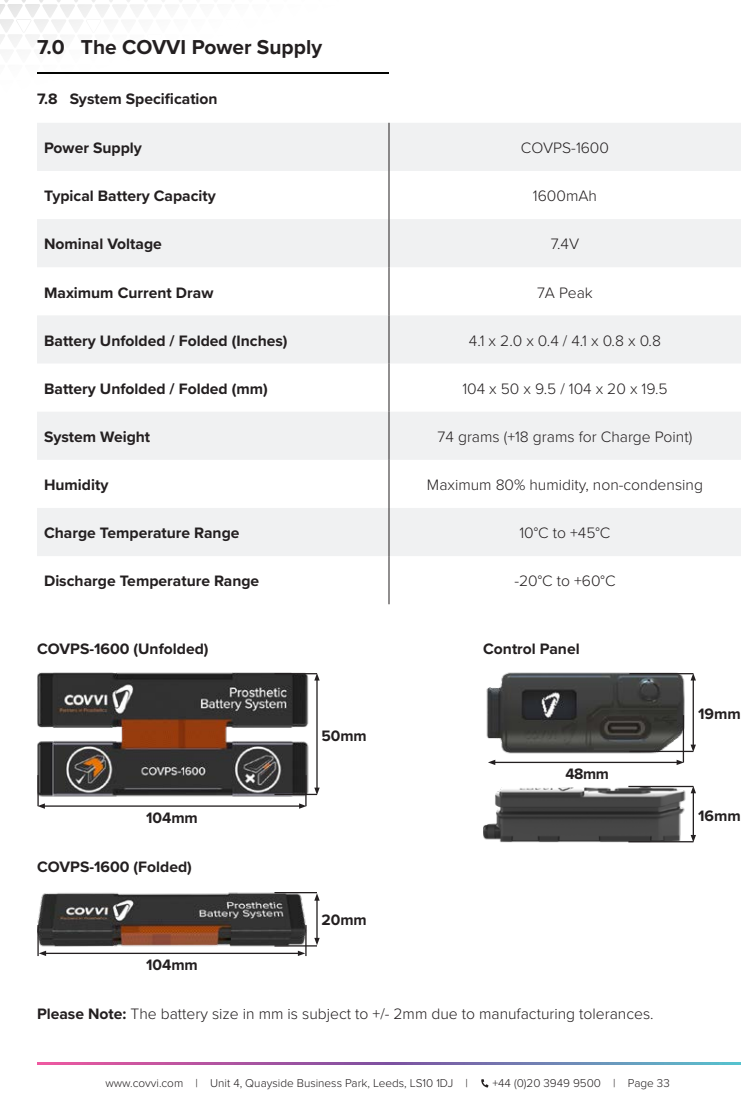
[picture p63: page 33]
www.covvi.com | Unit 4, Quayside Business Park, Leeds, LS10 1DJ |; +44 (0)20 3949 9500 | Page 33; COVPS-1600 (Unfolded); COVPS-1600 (Folded); 7.8 System Specification; Power Supply; COVPS-1600; Typical Battery Capacity; 1600mAh; Nominal Voltage; Maximum Current Draw; 7A Peak; Battery Unfolded / Folded (Inches); Battery Unfolded / Folded (mm); System Weight; 74 grams (+18 grams for Charge Point); Humidity; Maximum 80% humidity, non-condensing; Charge Temperature Range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

Please Note: The battery size in mm is subject to +/- 2mm due to manufacturing tolerances.

## 7.0 The COVVI Power Supply

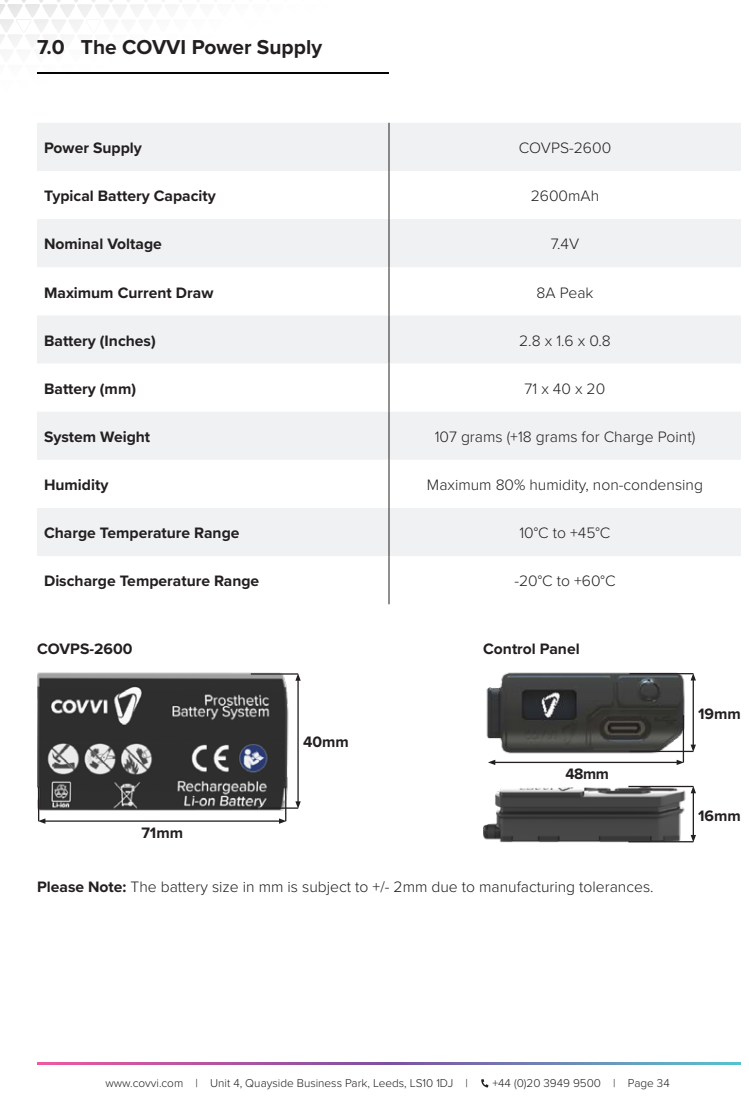
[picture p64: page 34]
www.covvi.com | Unit 4, Quayside Business Park, Leeds, LS10 1DJ |; +44 (0)20 3949 9500 | Page 34; COVPS-2600; Power Supply; Typical Battery Capacity; 2600mAh; Nominal Voltage; Maximum Current Draw; 8A Peak; Battery (Inches); Battery (mm); System Weight; 107 grams (+18 grams for Charge Point); Humidity; Maximum 80% humidity, non-condensing; Charge Temperature Range; Discharge Temperature Range; Control Panel

Please Note: The battery size in mm is subject to +/- 2mm due to manufacturing tolerances.

www.covvi.com | Unit 4, Quayside Business Park, Leeds, LS10 1DJ | | +44 (0)20 3949 9500 | | Page 35

As with all batteries, the capacity will degrade over time; we expect this to become noticeable after 12 months of use. The COVVI Power Supply will support 300 charge and discharge cycles. After this, the time it takes to fully flatten the batteries will become shorter. Replacement cells are available for both Power Supply versions.
It is imperative that you replace the batteries with those of the same capacity. COVSB-1600 is only compatible with the COVPS-1600 Power Supply, and COVSB-2600 is only compatible with the COVPS-2600 Power Supply. Deplete the old batteries until flat, and the limb no longer moves.
Disassemble the limb and replace the batteries. Reassemble the limb, connect the batteries to the USB-C charger and allow them to fully charge. If this initial charge is not conducted properly, it can negatively affect how the system calculates the remaining charge.
Check your local waste regulations to safely dispose of your old batteries.

### 7.9 Battery Replacement

## 7.0 The COVVI Power Supply

www.covvi.com | Unit 4, Quayside Business Park, Leeds, LS10 1DJ | | +44 (0)20 3949 9500 | | Page 36

Electromagnetic Compatibility, or EMC, refers to the ability of a device to function properly in its electromagnetic (EM) environment without causing or experiencing interference. The COVVI Hand is designed to ensure that it does not emit levels of electromagnetic energy that would cause interference with other nearby electronic devices, nor does it allow electromagnetic interference (EMI) from other devices to affect its performance. International standards and regulatory guidelines help minimise the risk of interference between electronic medical devices.
The COVVI Hand complies with the IEC 60601-1-2 standard, which outlines the requirements for medical electrical equipment in terms of basic safety and essential performance in relation to electromagnetic disturbances. This standard ensures that the device meets the necessary criteria for electromagnetic emissions and immunity to interference.
Please Note: The emission characteristics of the COVVI Hand make it suitable for use in both professional healthcare environments and residential settings, according to CISPR 11 Class B standards. This ensures that the device provides adequate protection against interference with radio communication services. In the unlikely event that interference does occur with nearby radio communication equipment, the user may need to take simple corrective actions, such as relocating or reorienting the device.

## 8.0 Electromagnetic Compatibility (EMC)

To prevent interference or operational issues, avoid placing this device directly next to or stacked with other electrical equipment. If such an arrangement is necessary, ensure both this device and the other equipment are monitored closely to verify that they are functioning correctly and are not affected by interference.

Only use approved accessories, electrodes, and cables provided or recommended by COVVI. Use of non-approved components may increase electromagnetic emissions or reduce the device’s electromagnetic immunity, potentially leading to improper operation or device malfunction.

Keep portable RF transmitters (including radios and mobile phones) at least 30cm (12 inches) away from the COVVI Hand. Failure to maintain this distance could result in performance degradation due to interference with the device’s electromagnetic sensitivity.

## 9.0 Component Compatibility

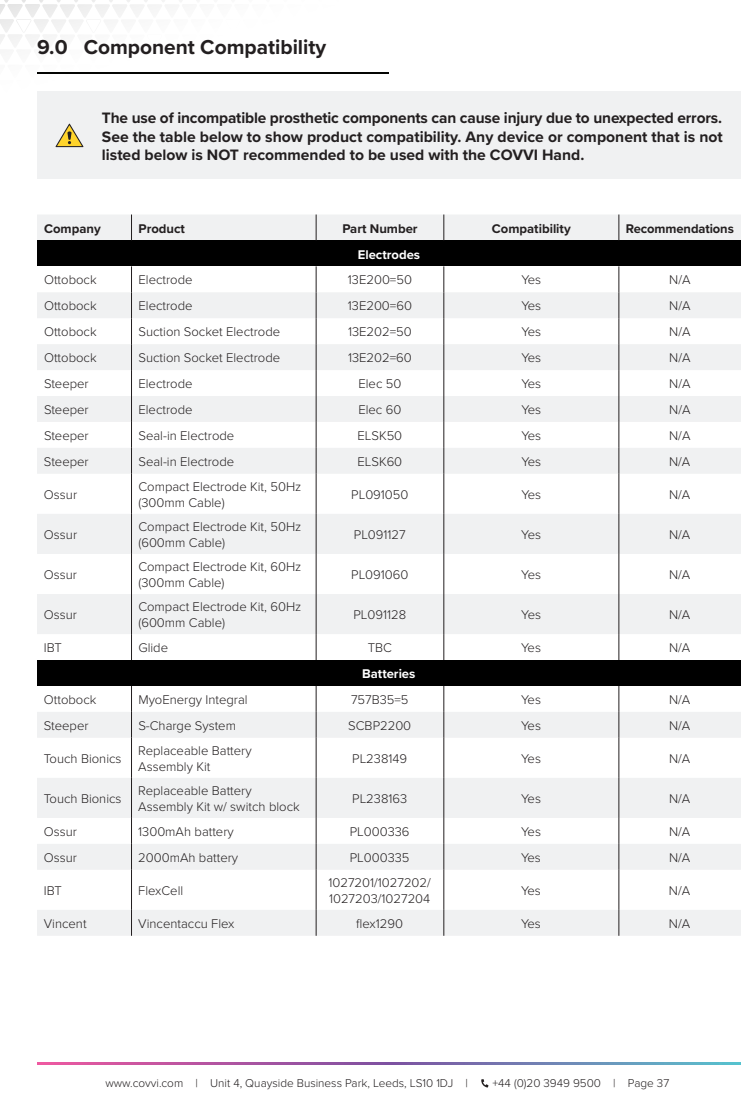
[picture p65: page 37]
www.covvi.com | Unit 4, Quayside Business Park, Leeds, LS10 1DJ |; +44 (0)20 3949 9500 | Page 37; Company; Product; Part Number; Compatibility; Recommendations; Electrodes; Ottobock; Electrode; Yes; Suction Socket Electrode; Steeper; Elec 50; Elec 60; Seal-in Electrode; ELSK50; ELSK60; Ossur; Compact Electrode Kit, 50Hz; (300mm Cable); (600mm Cable); Compact Electrode Kit, 60Hz; IBT; Glide; TBC; Batteries; MyoEnergy Integral; S-Charge System; SCBP2200; Touch Bionics; Replaceable Battery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

The use of incompatible prosthetic components can cause injury due to unexpected errors.
See the table below to show product compatibility. Any device or component that is not
listed below is NOT recommended to be used with the COVVI Hand.

## 9.0 Component Compatibility

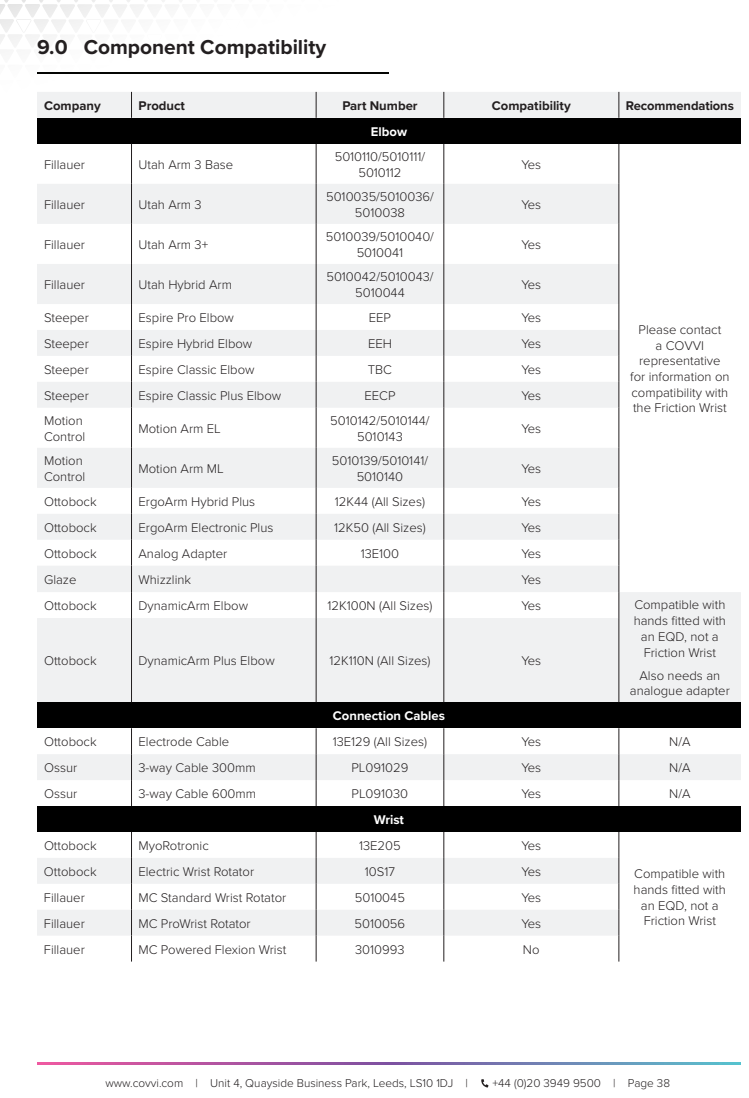
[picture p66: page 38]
www.covvi.com | Unit 4, Quayside Business Park, Leeds, LS10 1DJ |; +44 (0)20 3949 9500 | Page 38; Company; Product; Part Number; Compatibility; Recommendations; Elbow; Fillauer; Utah Arm 3 Base; Yes; Utah Arm 3+; Steeper; Espire Pro Elbow; EEP; Espire Hybrid Elbow; EEH; Espire Classic Elbow; TBC; Motion; Control; Motion Arm EL; Ottobock; ErgoArm Hybrid Plus; 12K44 (All Sizes); ErgoArm Electronic Plus; 12K50 (All Sizes); Analog Adapter; DynamicArm Elbow; 12K100N (All Sizes); Compatible with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

Fillauer | Utah Arm 3 | 5010035/5010036/ 5010038 | Yes

5010041 | Yes

Fillauer | Utah Hybrid Arm | 5010042/5010043/ 5010044 | Yes

Please contact
a COVVI
representative
for information on
compatibility with
the Friction Wrist

Steeper | Espire Classic Plus Elbow | EECP | Yes

5010143 | Yes

Motion Control | Motion Arm ML | 5010139/5010141/ 5010140 | Yes

Glaze | Whizzlink | Yes

hands fitted with an EQD, not a Friction Wrist Also needs an analogue adapter

Ottobock | DynamicArm Plus Elbow | 12K110N (All Sizes) | Yes

Compatible with
hands fitted with
an EQD, not a
Friction Wrist

www.covvi.com | Unit 4, Quayside Business Park, Leeds, LS10 1DJ | +44 (0)20 3949 9500 | Page 39

All systems which are compatible with a standard EQD. Compatible with a 7-8.4v battery supply. Compatible with 0-5v electrode signals.
WARNING: Use of the COVVI Hand adjacent to or stacked with other equipment not listed should be avoided because it could result in improper operation. If such use is necessary, the COVVI Hand and the other equipment should be observed to verify that they are operating normally.
WARNING: Use of accessories, transducers, and cables other than those specified or provided by COVVI Ltd. and COVVI USA INC could result in increased electromagnetic emissions or decreased electromagnetic immunity of the COVVI Hand and result in improper operation.
WARNING: Portable RF communications equipment (including peripherals such as antenna cables and external antennas) should be used no closer than 30cm (12 inches) to any part of the COVVI Hand, including cables specified by COVVI Ltd. and COVVI USA INC, as this could result in degradation of the performance of this equipment.

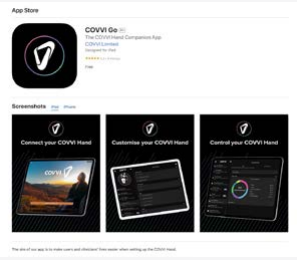
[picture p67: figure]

www.covvi.com | Unit 4, Quayside Business Park, Leeds, LS10 1DJ | | +44 (0)20 3949 9500 | | Page 40

Everything you need to configure a COVVI Hand is within COVVI Go, which is compatible with iOS version 12.0+ and Android version 10.0+. The App has been designed to support you and your patient through every step of your journey with a COVVI Hand. It is an intuitive platform, making programming easy and logical, ensuring you can configure your patient’s hand to best suit their daily activities and lifestyle to ensure they get the most out of it. The COVVI Hand comes with a default setup allowing for a smooth adaptation period for new users and efficient interchangeability from other prosthesis devices for existing users.
To download COVVI Go, go to our website www.covvi. com/covvi-go/ (https://www.covvi.com/covvi-go/) to find links to the Apple Store (for iOS)
and Google Play Store (for Android), where you can
download the App. You can also search for the App
directly in both stores by typing in ‘COVVI Go’. When the App has downloaded and installed, the icon will appear on your device’s home screen.

### 10.1 COVVI Go

## 10.0 COVVI Go

You can register within the App by opening it once it has finished installing, clicking on ‘Get Started’, then on ‘Sign Up’. Choose either ‘Prosthetic User’ or ‘Clinician’ and then click on ‘Next’ to fill out all the fields that are relevant to your account type. Once you complete all the required sections, you will receive an email with a link to validate your email and set your password.

You are responsible for adding your patients. To add a new user, go to the COVVI Portal, portal.covvi.com, click on ‘New User’, fill out their details and click on ‘Submit’. There is an option to activate a ‘Restricted Mode’ to simplify the process for new users, whereby certain features in the App will be disabled. This includes preventing users from accessing some of the more advanced settings within the App, while still allowing them to test out some of the options in the Hand Controls and Input Settings sections. This can also be deactivated at any point.
There is also a ‘Virtual Hand’ mode, which allows you to trial the App without connecting to a hand.

### 10.2 Registration

### 10.3 COVVI Portal

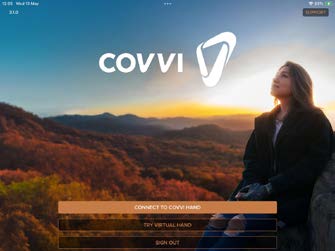
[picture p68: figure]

www.covvi.com | Unit 4, Quayside Business Park, Leeds, LS10 1DJ | | +44 (0)20 3949 9500 | | Page 41

## 10.0 COVVI Go

When you open the App, click on ‘Get Started’ and ‘Sign In’. There is an option to reset your password in case you forget it.
Once you have logged in, click on ‘Connect Hand’. The App will automatically begin searching for your hand. Click on ‘Connect’ next to the serial number to connect to your hand. The hand communicates using Bluetooth, which only stays activated for 60 seconds as a battery-saving feature. If you fail to connect before 60 seconds, turn the power to the hand off and back on again.
If you experience Bluetooth connectivity issues, hold the Dorsal Button on the back of the hand for 10
seconds. The E-Paper screen will say ‘RESET’ and
then ‘HELLO’.
If connectivity issues persist, please ensure the hand doesn’t have a low battery and that you don’t have Bluetooth interference.

### 10.4 Hand Selection

We advise that the first section of the configuration
completed with a user is the Input Settings section, to ensure the user can comfortably open and close the hand before trying out different Grips and Grip Triggers.
A user’s signals can be viewed on either the dials or on a graph view. In the ‘Input Dials’ tab, there is an Input Commands section that will display the triggers that are activated. There are three adjustable thresholds for both Input A and Input B: the ‘On’, ‘Max’ and ‘Co-Contraction’ thresholds.
The ‘On’ threshold is the signal strength needed for
the hand to move. The ‘Max’ threshold is the signal
strength needed for the hand to move at full speed.
The ‘Co-Contraction’ threshold will only appear if you map Co-Contraction in the Grip Triggers section. Near the top right of the screen, you can click on the ‘Input Settings’ tab to see the user’s signals on a graph. Click on the ‘Gear’ icon in the top right corner to bring up an additional console for more advanced settings. Here you can calibrate the thresholds for both the ’Open’ and ‘Close’ signals. Here, the user has to give the strongest signal they can comfortably produce during the five second timer. Click on ‘Confirm’ to save the data, or you can reset the test if they’re not satisfied with the results.

### 10.5 Input Settings

www.covvi.com | Unit 4, Quayside Business Park, Leeds, LS10 1DJ | +44 (0)20 3949 9500 | Page 42

## 10.0 COVVI Go

There are four tables available, each of which can be populated with up to six grips. All tables can be empty apart from Table A, which must always have one grip set as the hand’s primary grip. You can set up the tables with different combinations of grips that suit activities that the user performs in their day-to-day life. For example, you could populate one table with grips used at home, another with grips used at work and another with grips that are helpful for gardening or outdoor work.

### 10.6 Grip Tables

Default Grip Tables:
The default setup has two tables populated with the following grips. These are a mix of opposed and non-opposed grips. Tables C & D are empty and therefore disabled.
A | B | C | D
Tripod | Key | Empty | Empty
Power | Finger Point | Empty | Empty
Key | Tripod | Empty | Empty
Finger Point | Power | Empty | Empty
Empty | Empty | Empty | Empty
Empty | Empty | Empty | Empty

Adding Grips:
To add a grip, select the table you would like to populate and click on ‘Add New Grip’. Choose the desired grip from the list and then click on the back arrow to return to the table. The grip will now appear in the next available position. Grips are added one by one. If you are unsure of what a particular grip does, select one to see a video showing the product performing the selected grip.
Removing Grips:
To remove a grip, click on it and then select ‘No Grip’.

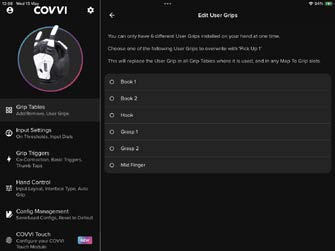
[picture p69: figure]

www.covvi.com | Unit 4, Quayside Business Park, Leeds, LS10 1DJ | | +44 (0)20 3949 9500 | | Page 43

## 10.0 COVVI Go

There are 14 standard grips available and a library of additional User Grips. To install a User Grip, the hand must have the Firmware Version 4.5.4 or higher. When you add grips to a table, a list will appear divided into different groups. Click on the one you would like to add to your table. You can add six user grips at once. Click on the back button, and the grip will now appear in the first list of grips under User Grips.

### 10.7 User Grips

There are 13 available Grip Triggers, 3 myo inputs and 10 passive input triggers on the product, all listed below.
Clicking on any Grip Trigger brings up the list of actions. The action assigned to each Grip Trigger is shown in copper underneath it. You can only assign a single action to a specific Grip Trigger; however, the same action can be set to multiple Grip Triggers if you desire.

The available Grip Triggers are:
Open/Open - An Open/Open signal is an open signal
to fully open the hand, followed by another open
signal. The second open signal must be sent before the Open/Open Time.
Long Hold Open - A Long Hold Open signal is an open signal that is maintained. The hand can be closed, partially closed or fully open. The signal must be maintained for the Long Hold Open Time once the hand is fully open.
Co-Contraction - Co-Contraction is when both inputs cross the Co-Contraction thresholds within a certain amount of time from the ‘On’ threshold being surpassed. The first input to cross the ‘On’ threshold initiates the Co-Contraction time (a timer customisable by the user), and if both inputs cross their Co-Contraction thresholds before the Co-Contraction time, there will be a successful Co-Contraction trigger.
In the Input Graph, the Co-Contraction thresholds must be higher than the ‘On’ thresholds. Co-Contraction can be assigned to any action; however, we would recommend that it is mapped to switching between devices, for example, an elbow to a wrist

### 10.8 Grip Triggers

www.covvi.com | Unit 4, Quayside Business Park, Leeds, LS10 1DJ | | +44 (0)20 3949 9500 | | Page 44

## 10.0 COVVI Go

Thumb Tip Hold - Pressure is applied to the Force Sensitive Resistor in the thumb for two seconds. Index Finger Tip Hold - Pressure is applied to the Force Sensitive Resistor in the index finger for two seconds.
Middle Finger Tip Hold - Pressure is applied to the Force Sensitive Resistor in the middle finger for two seconds.
Ring Finger Tip Hold - Pressure is applied to the Force Sensitive Resistor in the ring finger for two seconds. Little Finger Tip Hold - Pressure is applied to the Force Sensitive Resistor in the little finger for two seconds. Dorsal Button Hold - Hold the dorsal button next to the E-Paper screen for two seconds.

The available actions are:
Trigger Off - No action is assigned.
Next Grip - The next grip in the table is selected.
Previous Grip - The previous grip in the table is selected.
Next Table - The first grip in the next table is selected.
Previous Table - The first grip in the previous table is selected.
Switch to Table A / B / C / D - The first grip in Table A, B, C or D is selected.
Map to Grip - This action allows you to assign the Grip Trigger to go into a specific grip. The grip does not need to be in the grip tables to be mapped.
Toggle Auto Grip - Auto Grip will be turned on and off.
Toggle COVVI Touch Enabled - Enables COVVI Touch vibration feedback function.
Toggle COVVI Touch Repeat - Enables COVVI Touch repeat vibration function.

Non-Opposed Thumb Tap In - The thumb is tapped inwards and will move into an opposed position unless assigned to switch to a non-opposed grip, where it will remain in a non-opposed position.
Non-Opposed Thumb Tap Out - The thumb is tapped outwards when in a non-opposed position. If assigned to switch to a non-opposed grip, the thumb will remain in a non-opposed position. If assigned to switch to an opposed grip, the thumb will move into an opposed position.
Opposed Thumb Tap In - The thumb is tapped inwards when in an opposed position. If assigned to switch to an opposed grip, the thumb will remain in an opposed position. If assigned to switch to a non-opposed grip, the thumb will move into a non-opposed position.
Opposed Thumb Tap Out - The thumb is tapped outwards and will move into a non-opposed position unless assigned to switch to an opposed grip, where it will remain in an opposed position.

www.covvi.com | Unit 4, Quayside Business Park, Leeds, LS10 1DJ | | +44 (0)20 3949 9500 | | Page 45

## 10.0 COVVI Go

This section should only need programming once and may not even need any changes at all. The available options are:
1. Operating Mode: One available for dual site, two available for single site, or multiple digital electrodes for use with a pattern recognition system.
2. Input Layout: To order the open and close signals.

### 3. Interface Type: To choose what control interface

is being used.
*If your hand was purchased before April 2024, you
may see a different layout.
The available options to personalise in the Hand Control section are:
Beep - The beep is an audible alert to notify the user of any activity. It can be assigned to all functions, only power on and standby, only power on or it can be turned off.
Vibration - There is also the option to be alerted to activity with a vibration. Like with the beep, it can be assigned to all functions, only power on and standby, only power on, or it can be turned off.
Grip Settings - Here you can adjust the Grip Strength and Input Speed. The Grip Strength can be proportional to the user’s signal or fixed, where it can be manually set to one strength only. The Input Speed is the maximum speed of the digits.
Mode Options - This is dependent on the operating mode being used. You can adjust the time parameters for the Grip Triggers in dual-site use, or the timers for single-site use.
Digit Hold Time - This is the length of time you apply pressure on the FSRs for the Grip Trigger to activate. Moving the slider will increase or decrease the time in 0.5 second intervals, up to a maximum of 5 seconds. Auto Relax - After a certain period of inactivity, the hand moves into a relaxed position. The time parameter is user-adjustable. Moving the slider will allow users to turn it on and adjust the timer in one-minute intervals, up to a maximum of 10 minutes. Moving it all the way to the left will turn Auto Relax off.
Auto Grip - Auto Grip works in Power Grip, Tripod Grip, Precision Open and Precision Closed. If the fingers sense that an object is starting to slip, they reapply a small continuous force or pulse to gently grasp the object. It monitors the grip every half a second.
Switch to Primary Grip - After a certain period of inactivity, the current grip changes back into the primary grip in Table A. The time parameter is user-adjustable by moving the slider in 15 second intervals, up to a maximum of one minute. Moving it all the way to the left will turn ‘Switch to Primary Grip’ off.
Thumb Mode - The thumb can be set as one of two options. In ‘Latched’ mode, the thumb will automatically rotate to the required grip position and stay there for the selected grip. In ‘Dynamic’ mode, the thumb will rotate to the central position when the hand is open for a more natural look, and then rotate to the required position when forming a grip.

### 10.9 Hand Control

www.covvi.com | Unit 4, Quayside Business Park, Leeds, LS10 1DJ | | +44 (0)20 3949 9500 | | Page 46

Mode Specific Parameters
For Dual Site Open/Close, the following parameters can be established:
Open/Open Time - This is the length of time in which a second open signal must be sent after the hand is fully opened, or after the first open signal, for the Open/Open Grip Trigger to work.
Long Hold Open Time - This is the length of time an open signal must be maintained once the hand is fully opened for the Long Hold Open Grip Trigger to work. Co-Contraction Time - This is the length of time during which both inputs must pass the Co-Contraction thresholds after the On threshold has
been reached.

For Fast Open/Slow Close, the following parameters can be established:
Fast Open / Slow Close Time - A signal sent within this time is interpreted as an open signal, and a signal sent after this time is interpreted as a close signal.
Long Hold Open Time - This is the length of time an open signal must be maintained once the hand is fully opened for the Long Hold Open Grip Trigger to work.

For Single Site Alternating, the following parameters can be defined:
Direction Change Time - A signal sent after this time will change the direction of the hand, and a signal sent within this time will keep the direction of the hand the same.
Long Hold Open Time - This is the length of time an open signal must be maintained once the hand is fully opened for the Long Hold Open Grip Trigger to work.

## 10.0 COVVI Go

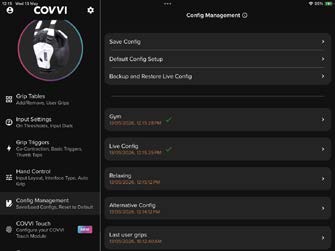
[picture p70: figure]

www.covvi.com | Unit 4, Quayside Business Park, Leeds, LS10 1DJ | | +44 (0)20 3949 9500 | | Page 47

In Config Management, you have three options:
1. Save Config allows you to save a new configuration to the cloud or overwrite an existing config, so there is always a backup available. If a config is saved with a name that already exists, a confirmation message will appear to ask if you want it to be overwritten.
2. Default Config Setup allows you to select a COVVI configuration from a range of options, including configurations that are compatible with third-party control systems, such as COAPT.
3. Backup and Restore Live Config is to transfer
configurations between devices.
Underneath these options, there is the Config Library, where you can see all configurations that you have saved to the product. To restore a configuration, click on the desired one and then on ‘Restore’.

The COVVI Touch module works in tandem with the
COVVI Hand to produce vibrational feedback, which
is sent to a user’s residual limb when their bionic hand comes in contact with an object.
With sensors already present in each digit of the COVVI Hand, COVVI Touch unlocks the technology for a new purpose - letting users know when their bionic hand is touching or holding an object without the need to rely solely on visuals. This provides a better sense of spatial awareness, grasp and even the potential to recognise the size, shape and density of objects. Settings can be adjusted in this section of the App
for elements like deciding which grips to receive
feedback in, the strength of the vibration, and how
the feedback is relayed (a single pulse, continuous vibration when in contact, or a recurring pulse). Please Note: COVVI Touch is not compatible when fitted with the COVVI Hand Friction Wrist. It can only be installed on prosthetic systems that feature the COVVI Hand, with either a Flex Wrist or a Straight Wrist. For more information about being fitted with COVVI Touch, please visit our website: www.covvi.com/covvi-hand/covvi-touch (https://www.covvi.com/covvi-hand/covvi-touch/)

## 10.0 COVVI Go

### 10.10 Config Management

### 10.11 COVVI Touch

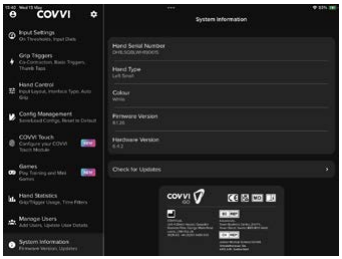
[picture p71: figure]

www.covvi.com | Unit 4, Quayside Business Park, Leeds, LS10 1DJ | | +44 (0)20 3949 9500 | | Page 48

## 10.0 COVVI Go

This section provides a range of training programs to practice different operations of the COVVI Hand. For example, our Training Game is focused on fine-tuning open and close signals by holding a certain signal within a fixed area for different lengths of time. All the games have additional options to customise a user’s experience, as well as multiple difficulty options, so users can build up competency with the COVVI Hand at their own pace.

### 10.12 Games

This section displays a range of useful statistics about the COVVI Hand. You can see the top five Grips and Grip Triggers used in the current month, which can also be filtered to show other periods of time as well. By pressing ‘View More’, you can see the complete stat history for each individual Grip and Grip Trigger. Selecting any one of these then shows you the detailed history of this information, displayed on a graph.

### 10.13 Hand Statistics

In this section of the App, you can find basic information about the COVVI Hand, including the hand’s Serial Number and the current Firmware Version.
There is also the option to ‘Check For Updates’, which will look to see if there are any software updates that are currently available. If there are any software updates, the App will then guide you through this process of updating.

### 10.14 System Information

www.covvi.com | Unit 4, Quayside Business Park, Leeds, LS10 1DJ | | +44 (0)20 3949 9500 | | Page 49

## 10.0 COVVI Go

To continuously improve the COVVI Hand, an integrated update feature runs on the device firmware. These updates include improvements, new features, bug fixes, etc... These updates do not require the user to send their hand into a COVVI repair centre to be updated; they can be downloaded to the hand remotely from the cloud.
Click on ‘Check For Updates’. If there are updates available, you must update the Firmware first, then the Gateware.
To perform the update, click on it and select ‘Download and Install’. The update first downloads
from the App onto the hand, then the update is
installed to the hand. This process can take up to 30
minutes, so we recommend keeping the hand close to the device to ensure a strong Bluetooth connection is maintained, and download speeds are optimal. The E-Paper screen will change to indicate an update is taking place. The hand must remain connected to a power source until the update is complete. If it is disconnected from power, it will stop the update, which means it will need to start again. It cannot be connected to a charger during the update because this will turn the power off to the hand. Once the update is complete, the hand will reboot. Repeat the process for the Gateware.

### 10.15 Software Update

The COVVI Remote Assist feature allows a COVVI
Representative to provide real-time support to
clinicians and users to implement instant configuration changes to the live configuration, software updates, and perform troubleshooting to any COVVI Hand, anywhere in the world. Accredited clinicians have access to this platform to do the same for users. From the main menu of the App, you can access the Remote Assist feature by tapping the ‘Gear’ icon in the top right corner, and then selecting ‘ COVVI Remote Assist’ from the Console.
Please Note: We can ONLY connect to the hand if a
clinician and/or COVVI is notified first, and a meeting
time is confirmed. Ensure that the window is kept open
in the App while we connect to the hand. You will know when we are connected, as under technician status, it will say ‘Connected’ in green.

### 10.16 Remote Assist

www.covvi.com | Unit 4, Quayside Business Park, Leeds, LS10 1DJ | | +44 (0)20 3949 9500 | | Page 50

COVVI offers a 24-month manufacturer’s warranty for the hand and a 3-month manufacturer’s warranty for the glove, both included with the purchase of the hand, which take effect from the date of invoice. If no Extended Warranty is purchased, all of COVVI’s obligations shall cease upon the expiration of the manufacturer’s warranty.

Please read these Warranty Terms and Conditions carefully before using all COVVI products and services. We may modify these Terms for any reason at any time, by posting a new version on our website; these changes do not affect rights and obligations that were defined prior to such changes. There are various limited warranties that apply to manufactured products and goods purchased from COVVI.

11.1 24-Month Manufacturer’s Warranty

### 11.2 Optional Extended Warranty

### 11.3 Additional Information

## 11.0 Warranty

COVVI offers an extended warranty for an additional year, covering the hand for 36 months, or an additional three years covering the hand for 60 months. The extended warranties have an additional cost and must be purchased with the hand.

Products are subject to evaluation for warranty. COVVI is not responsible for normal wear, and/or damage caused by excessive force, and/or excessive usage beyond the technical design and/or beyond its reasonable means. COVVI warrants its products against defects in material and workmanship within the warranty period.
Limitation in those instances where changes, alterations or modifications are made in materials at the request or instruction of the customer, the customer agrees not to claim or commence suit against COVVI based on any such disclaimed warranties.
Our obligation is limited only to the repair and replacement of defective parts within the warranty period or, at the sole discretion of COVVI, to refund the purchase price of a full refund, partial refund, or no refund, depending on the condition of the return. The possible refund will be given, subject to our Quality Department.

www.covvi.com | Unit 4, Quayside Business Park, Leeds, LS10 1DJ | | +44 (0)20 3949 9500 | | Page 51

To the fullest extent permitted by law COVVI Ltd. and its affiliates, directors, officers, employees, partners, contractors, or agents will not be liable for any losses or damages whether direct, indirect, incidental, special, punitive, or consequential resulting from the use of the COVVI Hand and associated products, irrespective of whether the Clinician or User has been advised or otherwise might have anticipated the possibility of such loss or damage.
COVVI Ltd. and its affiliates, directors, officers, employees, partners, contractors, or agents shall not be responsible for strikes, labour slowdowns, war, terrorism, riots, severe weather conditions, natural disasters, acts of God or any other forces beyond the reasonable control of COVVI which may result in direct, indirect, incidental, special, punitive, or consequential losses or damage.

Only the COVVI Hand is serviceable; all COVVI supporting products are designed to be maintenance-free. When any COVVI product is sent in for repairs or to be evaluated for faults, it must be returned to COVVI completely assembled and not tampered with. COVVI has the right to void the warranty of all products that have any type of modifications or damage caused by any unauthorised or untrained personnel. The manufacturer’s and extended warranty do not cover repairs needed as a result of:
- Any intentional damage or neglect
- Any alterations or attempted repairs without written consent from the Supplier
- Any damage or defects arising due to not following the safety precautions as stated in the Instructions for Use and Technical Manual
- Any damage or defects arising from improper installation
- Any damage or defects arising from using the Hands with incompatible products
- Any damage or defects arising due to using, transporting or storing the Hands outside of the parameters as stated in the Environmental Conditions section of the Instructions for Use and Technical Manual
- Any damage or defects arising due to any illegal activities involving the Hands
- Any damage or defects arising due to accidents while operating a motor vehicle using the Hands
- Any damage or defects due to use by anyone other than the owner
COVVI reserves the right not to repair any Hands under the Extended Warranty if the Customer makes any further use of such Hands after giving notice of a defect.
Should the product be under warranty and have any manufacturing and/or workmanship defects, the part(s) will be replaced at no charge. The warranty holder will be informed of any and all defects that are covered and not covered under warranty. Any product out of warranty that is sent in to COVVI will be evaluated by our Quality Department and quoted with repair parts and labour as required. Once the repair estimate is sent to the customer, they will have a 60-day approval period. Once the 60-day approval period expires, COVVI has the right to ship the device back to the customer.

### 12.1 Limited Liability

## 12.0 Warranty Service and Repairs

www.covvi.com | Unit 4, Quayside Business Park, Leeds, LS10 1DJ | | +44 (0)20 3949 9500 | | Page 52

The standard return period for any COVVI product is 14 days from the date of receipt at the shipping address. If you or your patient would like to request a refund for any COVVI products, you must complete the Return Form on the COVVI website (www.covvi.com/contact/return-request) explaining the reason, and the items must be shipped in their original condition and packaging to COVVI for inspection.
COVVI is under no obligation to refund:
- Any Goods that have been used by your patient.
- Any Goods that are damaged after delivery to the shipping address.
- Any requests received after the standard return period.
The returns policy only applies to products manufactured by COVVI Ltd. and COVVI USA INC and does not apply to products distributed by COVVI Ltd. and COVVI USA INC.

In the event of any serious incident involving the product, it is essential that it is reported promptly to the manufacturer and the competent authority of the member state in which the user is established, to maintain the highest standards of safety and compliance. Please report any incident to COVVI Ltd. or COVVI USA INC by emailing customerservice@covvi.com.
Please ensure you include the serial number of the COVVI Hand(s) affected when you reach out to us, which can be found on the base of the device, starting with ‘CV’ and continuing clockwise. If you have a loaner or demo hand, then this serial number begins with ‘LN’.
Ensuring that any issues are reported helps maintain the highest standards of safety and compliance.

### 13.1 Returns

## 13.0 Device Problem Reporting

Flex Wrist | Straight Wrist | Friction Wrist

www.covvi.com | Unit 4, Quayside Business Park, Leeds, LS10 1DJ | | +44 (0)20 3949 9500 | | Page 53

## 14.0 Disposal

COVVI products should not be disposed of with regular household waste. Proper disposal of COVVI products will avoid having a detrimental impact on health and the environment. For more details on collection and proper disposal, please check with your local authority.
COVVI packaging should be disposed of through your local facilities. By disposing of the packaging in the proper manner, you help to avoid possible hazards for the environment and public health. Observe national registration requirements for importers according to the EU WEEE Directive 2012/19/EU.
All the components of this product and articles contained within have been chosen and evaluated in accordance with compliance with the EU RoHS directive 2011/65/EU: The products are produced with restricted use of hazardous substances to protect the environment.
All the components of this product and articles contained within have been chosen and evaluated in accordance with compliance for the Regulation (EC) 1907/2006 of the European Parliament, “Registration, Evaluation, and Authorization of Chemicals (REACH): The product and articles contained within DO NOT CONTAIN any of the 247 REACH - Substances of Very High Concern (SVHC) as updated by ECHA on January 21, 2025.
For the full declaration of conformity statements, please use the links below to view the documents: www.covvi.com/about/declaration-of-conformity

## REACH

COMPLIANT | RoHS

www.covvi.com | Unit 4, Quayside Business Park, Leeds, LS10 1DJ | +44 (0)20 3949 9500 | Page 54

## 15.0 Symbols Used

Indicates that the product conforms with the essential requirements and provisions of MDR 2017/745.

Indicates that the user should refer to the instruction manual or consult the instructions for use before operating the medical device. It directs the user to read the accompanying documentation for safety, operational, or maintenance instructions.

Identifies the entity responsible for the design, production, packaging, and labelling of the device.

A unique identifier assigned to each device that differentiates it from others. Used for tracking and recalls.

A unique identifier assigned to each device that differentiates it from others. Used for tracking and recalls.

Indicates that the device is part of a specific lot or batch, and the accompanying number identifies that particular lot or batch for tracking purposes.
Indicates that the device is a specific product from the manufacturer’s catalogue, and the accompanying number identifies that particular product for reordering or reference purposes.
Indicates that the product is classified as a medical device under relevant regulatory requirements, such as EU Medical Device Regulation (MDR) 2017/745. It helps distinguish medical devices from other products.

Below are the symbols used to convey information about the COVVI product range, which is derived from standards EN 980:2008, ISO 15223, IEC 60417 and IEC 60878:

Indicates that the device must be protected from water or moisture exposure, which could damage the internal components.

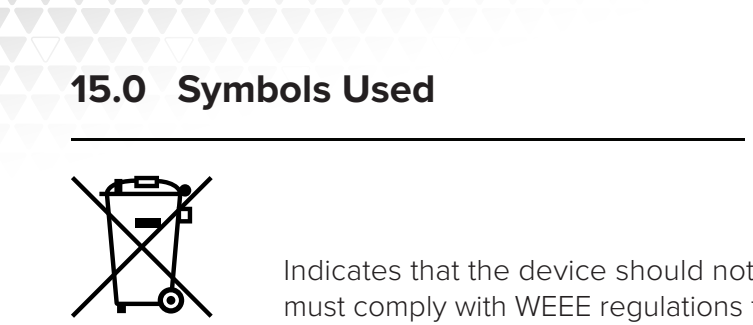
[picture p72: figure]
15.0 Symbols Used

www.covvi.com | Unit 4, Quayside Business Park, Leeds, LS10 1DJ | +44 (0)20 3949 9500 | Page 55

Indicates that the device should not be disposed of with regular household waste and must comply with WEEE regulations for proper electronic waste disposal.

Specifies the temperature range within which the device can be safely stored or operated.

Indicates the range of humidity the device can be safely exposed to or operated within.

Specifies the range of atmospheric pressure to which the device can be exposed.

The UKCA marking is the conformity marking used for products being placed on the market in Great Britain.

Indicates the name and address of the Authorised Representative in the Switzerland for the medical device. The authorised representative acts on behalf of the manufacturer in ensuring that the manufacturer meets regulatory requirements in Switzerland.

Indicates the name and address of the Authorised Representative in the European Union (EU) for the medical device. The authorised representative acts on behalf of the manufacturer in ensuring that the manufacturer meets regulatory requirements in Europe, especially for non-EU manufacturers.

www.covvi.com | Unit 4, Quayside Business Park, Leeds, LS10 1DJ | | +44 (0)20 3949 9500 | | Page 56

Indicates that the device has a Type BF (Body Floating) applied part that provides a degree

## Li-ion

Indicates that the product contains a Lithium-Ion (Li-ion) battery and must be recycled properly. It is a general environmental symbol that emphasise the need to dispose of the battery in an environmentally responsible manner.

This symbol warns against crushing the device or battery. Crushing the device could cause internal damage, including potential battery rupture, which may lead to fire or explosion.

Indicates that the device or battery should not be disassembled. Opening or tampering with the internal components can result in dangerous conditions, such as exposure to chemicals, electric shock, or fire hazards.

Warns against exposing the battery or device to fire or high temperatures. Doing so could cause the battery to overheat, catch fire, or even explode.

Indicates that the electronic device complies with the FCC regulations regarding electromagnetic interference (EMI) and radio frequency emissions, as defined under Title 47 CFR Part 15 (and other applicable parts)

A line with a solid line above a dashed line indicates that the device operates on direct current (DC).
A battery icon with a lightning bolt or an arrow indicates that the device or battery is charging or capable of being recharged.

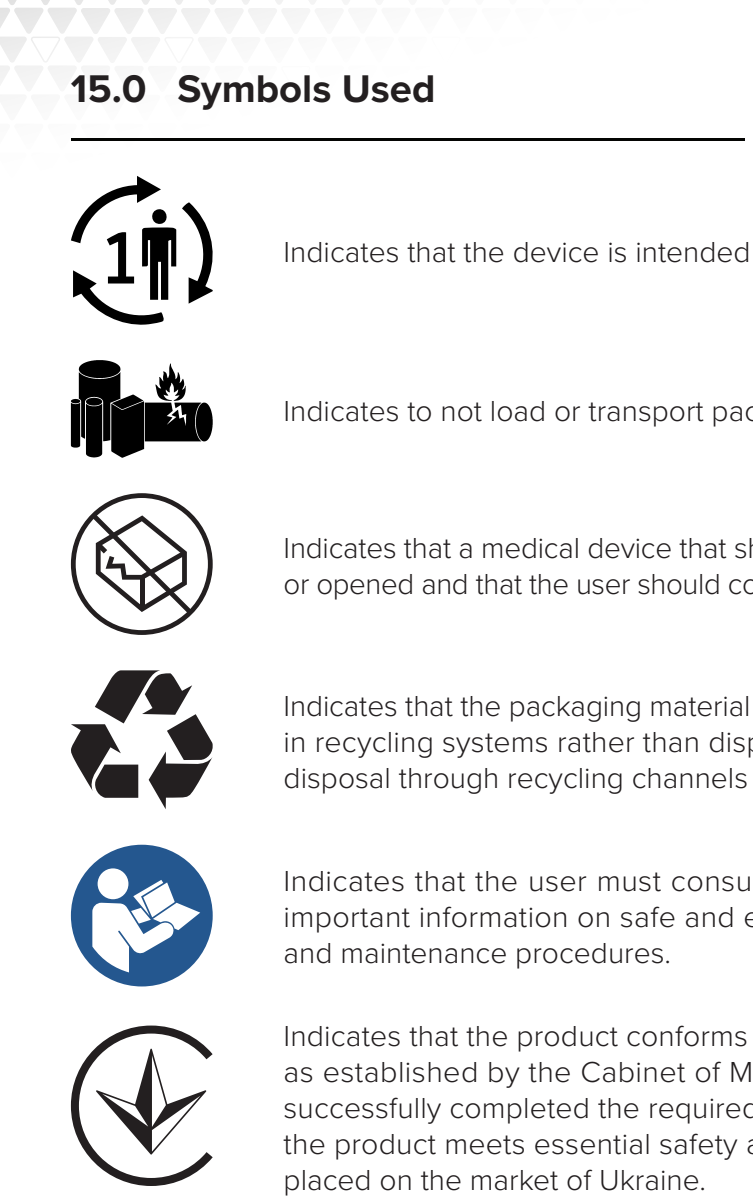
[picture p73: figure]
15.0 Symbols Used; placed on the market of Ukraine.; and maintenance procedures.

www.covvi.com | Unit 4, Quayside Business Park, Leeds, LS10 1DJ | | +44 (0)20 3949 9500 | | Page 57

Indicates that the device is intended for use by a single patient, but for multiple times.

Indicates to not load or transport package if damaged.

This device complies with Part 15 of the FCC Rules. Operation is subject to the following two conditions: (1) this device may not cause harmful interference, and (2) this device must accept any interference received, including interference that may cause undesired operation.

- United States/FCC ID: A8TBM71S2
- Canada IC: 12246A-BM71S2
- Europe/CE
- China/SRRC: CMIIT ID: 2016DJ5890

R Japan: 005-101150
South Korea: MSIP-CRM-mcp-BM71BLES1FC2 CCAN16LP0011T7

Indicates that the product conforms to the applicable Technical Regulations of Ukraine, as established by the Cabinet of Ministers of Ukraine, and that the manufacturer has successfully completed the required conformity assessment procedure. It confirms that the product meets essential safety and performance requirements and can be lawfully

Indicates that a medical device that should not be used if the package has been damaged or opened and that the user should consult the instructions for use for additional information

Indicates that the packaging material or product can be collected, processed, and reused in recycling systems rather than disposed of as waste. The symbol encourages proper disposal through recycling channels according to local regulations.

Indicates that the user must consult the instructions for use (IFU) or user manual for important information on safe and effective use, warnings, precautions, or installation www.covvi.com | Unit 4, Quayside Business Park, Leeds, LS10 1DJ | +44 (0)20 3949 9500 | Page 58

## 16.0 Declaration of Conformity

Declaration of Conformity for:
The COVVI Hand (UK, UKCA Marking)

We hereby declare, under the manufacturer’s sole responsibility, that the products described in this document are in conformity with the applicable provisions of the Medical Devices Regulations 2002 (SI 2002 No. 618, as amended) and The Electromagnetic Compatibility Regulations 2016 (SI 2016 No. 1091), and are manufactured and released in accordance with the Quality Management System in force on the date of issue of this declaration. The UKCA marking may be affixed.

Product Name: | COVVI Hand
Legal Manufacturer: | COVVI Ltd., Unit 4 (Direct House), Quayside Business Park,
| George Mann Road, Leeds, LS10 1DJ, United Kingdom
EU Single Registration Number
(SRN): | GB-MF-000033926
Basic UDI-DI: | 506072613GMN001WU
Global Medical Device
Nomenclature Code: | 41497
Applicable Legislations And
Standards: | As per Appendix I - Applicable Legislations and Standards
Configurations And Variants: | As per Appendix II - Product Listing/Schedule
Intended Purpose: | The COVVI Hand is intended for individuals with unilateral or bilateral upper limb
| loss or congenital limb deficiency. It is designed exclusively for use in exoprosthetic
| fittings of the upper limbs, providing functional and assistive support to users.
Medical Device Classification: | Class 1 [Rule 12]
Notified Body: | N/A
UKCA Certificate: | N/A
UK Approved Body Name: | Not Applicable for Class I
UK Approved Body Identification
Number: | Not Applicable for Class I
Medical Device Regulation Assessment Route: | In conformity with the applicable requirements of the Medical Devices Regulations
| 2002 (SI 2002 No. 618, as amended), commonly referred to as UK MDR 2002.

Full Declaration of Conformity Document
Please click the following link to view the full COVVI Hand Declaration of Conformity (UK): www.covvi.com/wp-content/uploads/documents/DoC/Declaration-Of-Conformity-UK-COVVI-Hand.pdf www.covvi.com | Unit 4, Quayside Business Park, Leeds, LS10 1DJ | +44 (0)20 3949 9500 | Page 59

## 16.0 Declaration of Conformity

Declaration of Conformity for:
The COVVI Hand (EU, CE Marking)

We herewith declare, under the manufacturer’s sole responsibility, that the products described in this document are in conformity with the relevant requirements of Regulation (EU) 2017/745 of the European Parliament and of the Council of 5 April 2017 concerning Medical Devices and Directive 2014/30/EU of the European Parliament and of the Council of 26 February 2014 on the harmonisation of the laws of the Member States relating to electromagnetic compatibility (recast) and are manufactured and released according to the provision of the quality management system in force on the date of issue of this declaration and the CE Mark may be affixed.

Product Name: | COVVI Hand
Legal Manufacturer: | COVVI Ltd., Unit 4 (Direct House), Quayside Business Park,
| George Mann Road, Leeds, LS10 1DJ, United Kingdom
Single Registration Number (SRN): | GB-MF-000033926
Basic UDI-DI: | 506072613GMN001WU
Global Medical Device
Nomenclature Code: | 41497
European Medical Device
Nomenclature Code: | Y061899
Applicable Legislations And
Standards: | As per Appendix I - Applicable Legislations and Standards
Configurations And Variants: | As per Appendix II - Product Listing/Schedule
Intended Purpose: | The COVVI Hand is intended for individuals with unilateral or bilateral upper limb
| loss or congenital limb deficiency. It is designed exclusively for use in exoprosthetic
| fittings of the upper limbs, providing functional and assistive support to users.
Medical Device Classification: | Class 1 [Rule 13]
Notified Body: | N/A
CE Certificate: | N/A
EU Authorised Representative: | Advena Limited, Tower Business Centre, 2nd Flr.,
| Tower Street, Swatar, BKR 4013, Malta
EU Authorised Representative
SRN: | MT-AR-000000234
Medical Device Regulation Assessment Route: | In conformity with Annexes II and III, the Declaration of Conformity has been drawn
| up in accordance with Article 19 of Regulation (EU) 2017/745.

Full Declaration of Conformity Document
Please click the following link to view the full COVVI Hand Declaration of Conformity (EU): www.covvi.com/wp-content/uploads/documents/DoC/Declaration-Of-Conformity-EU-COVVI-Hand.pdf www.covvi.com | Unit 4, Quayside Business Park, Leeds, LS10 1DJ | +44 (0)20 3949 9500 | Page 60

## 16.0 Declaration of Conformity

Declaration of Conformity for:
The COVVI Wrist Lamination Kit (UK, UKCA Marking)

We hereby declare, under the manufacturer’s sole responsibility, that the products described in this document are in conformity with the applicable provisions of the Medical Devices Regulations 2002 (SI 2002 No. 618, as amended) and The Electromagnetic Compatibility Regulations 2016 (SI 2016 No. 1091), and are manufactured and released in accordance with the Quality Management System in force on the date of issue of this declaration. The UKCA marking may be affixed.

Full Declaration of Conformity Document
Please click the following link to view the full COVVI Wrist Lamination Kit Declaration of Conformity (UK): www.covvi.com/wp-content/uploads/documents/DoC/Declaration-Of-Conformity-UK-COVVI-Wrist-Lamination-Kit.pdf
Product Name: | Wrist Lamination Kit
Legal Manufacturer: | COVVI Ltd., Unit 4 (Direct House), Quayside Business Park,
| George Mann Road, Leeds, LS10 1DJ, United Kingdom
EU Single Registration Number
(SRN): | GB-MF-000033926
Basic UDI-DI: | 506072613GMN003WY
Global Medical Device
Nomenclature Code: | 41086
Applicable Legislations And
Standards: | As per Appendix I - Applicable Legislations and Standards
Configurations And Variants: | As per Appendix II - Product Listing/Schedule
Intended Purpose: | The COVVI Wrist Lamination Kit is intended to transmit power and control signals to
| upper limb exoprosthetic terminal devices.
Medical Device Classification: | Class 1 [Rule 12]
Notified Body: | N/A
UKCA Certificate: | N/A
UK Approved Body Name: | Not Applicable for Class I
UK Approved Body Identification
Number: | Not Applicable for Class I
Medical Device Regulation Assessment Route: | In conformity with the applicable requirements of the Medical Devices Regulations
| 2002 (SI 2002 No. 618, as amended), commonly referred to as UK MDR 2002.

www.covvi.com | Unit 4, Quayside Business Park, Leeds, LS10 1DJ | +44 (0)20 3949 9500 | Page 61

## 16.0 Declaration of Conformity

Declaration of Conformity for:
The COVVI Wrist Lamination Kit (EU, CE Marking)

We herewith declare, under the manufacturer’s sole responsibility, that the products described in this document are in conformity with the relevant requirements of Regulation (EU) 2017/745 of the European Parliament and of the Council of 5 April 2017 concerning Medical Devices and Directive 2014/30/EU of the European Parliament and of the Council of 26 February 2014 on the harmonisation of the laws of the Member States relating to electromagnetic compatibility (recast) and are manufactured and released according to the provision of the quality management system in force on the date of issue of this declaration and the CE Mark may be affixed.

Product Name: | Wrist Lamination Kit
Legal Manufacturer: | COVVI Ltd., Unit 4 (Direct House), Quayside Business Park,
| George Mann Road, Leeds, LS10 1DJ, United Kingdom
Single Registration Number (SRN): | GB-MF-000033926
Basic UDI-DI: | 506072613GMN003WY
Global Medical Device
Nomenclature Code: | 41086
European Medical Device
Nomenclature Code: | Y061899
Applicable Legislations And
Standards: | As per Appendix I - Applicable Legislations and Standards
Configurations And Variants: | As per Appendix II - Product Listing/Schedule
Intended Purpose: | The COVVI Wrist Lamination Kit is intended to transmit power and control signals to
| upper limb exoprosthetic terminal devices.
Medical Device Classification: | Class 1 [Rule 13]
Notified Body: | N/A
CE Certificate: | N/A
EU Authorised Representative: | Advena Limited, Tower Business Centre, 2nd Flr.,
| Tower Street, Swatar, BKR 4013, Malta
EU Authorised Representative
SRN: | MT-AR-000000234
Medical Device Regulation Assessment Route: | In conformity with Annexes II and III, the Declaration of Conformity has been drawn
| up in accordance with Article 19 of Regulation (EU) 2017/745.

Full Declaration of Conformity Document
Please click the following link to view the full COVVI Wrist Lamination Kit Declaration of Conformity (EU): www.covvi.com/wp-content/uploads/documents/DoC/Declaration-Of-Conformity-EU-COVVI-Wrist-Lamination-Kit.pdf www.covvi.com | Unit 4, Quayside Business Park, Leeds, LS10 1DJ | +44 (0)20 3949 9500 | Page 62

## 16.0 Declaration of Conformity

Declaration of Conformity for:
The COVVI Power Supply (UK, UKCA Marking)

We hereby declare, under the manufacturer’s sole responsibility, that the products described in this document are in conformity with the applicable provisions of the Medical Devices Regulations 2002 (SI 2002 No. 618, as amended) and The Electromagnetic Compatibility Regulations 2016 (SI 2016 No. 1091), and are manufactured and released in accordance with the Quality Management System in force on the date of issue of this declaration. The UKCA marking may be affixed.

Full Declaration of Conformity Document
Please click the following link to view the full COVVI Power Supply Declaration of Conformity (UK): www.covvi.com/wp-content/uploads/documents/DoC/Declaration-Of-Conformity-UK-COVVI-Power-Supply.pdf
Product Name: | COVVI Power Supply
Legal Manufacturer: | COVVI Ltd., Unit 4 (Direct House), Quayside Business Park,
| George Mann Road, Leeds, LS10 1DJ, United Kingdom
EU Single Registration Number
(SRN): | GB-MF-000033926
Basic UDI-DI: | 506072613GMN004X2
Global Medical Device
Nomenclature Code: | 36534
Applicable Legislations And
Standards: | As per Appendix I - Applicable Legislations and Standards
Configurations And Variants: | As per Appendix II - Product Listing/Schedule
Intended Purpose: | The COVVI Power Supply is intended to power externally controlled upper limb
| prosthetic hands.
Medical Device Classification: | Class 1 [Rule 12]
Notified Body: | N/A
UKCA Certificate: | N/A
UK Approved Body Name: | Not Applicable for Class I
UK Approved Body Identification
Number: | Not Applicable for Class I
Medical Device Regulation Assessment Route: | In conformity with the applicable requirements of the Medical Devices Regulations
| 2002 (SI 2002 No. 618, as amended), commonly referred to as UK MDR 2002.

www.covvi.com | Unit 4, Quayside Business Park, Leeds, LS10 1DJ | +44 (0)20 3949 9500 | Page 63

## 16.0 Declaration of Conformity

Declaration of Conformity for:
The COVVI Power Supply (EU, CE Marking)

We herewith declare, under the manufacturer’s sole responsibility, that the products described in this document are in conformity with the relevant requirements of Regulation (EU) 2017/745 of the European Parliament and of the Council of 5 April 2017 concerning Medical Devices and Directive 2014/30/EU of the European Parliament and of the Council of 26 February 2014 on the harmonisation of the laws of the Member States relating to electromagnetic compatibility (recast) and are manufactured and released according to the provision of the quality management system in force on the date of issue of this declaration and the CE Mark may be affixed.

Product Name: | COVVI Power Supply
Legal Manufacturer: | COVVI Ltd., Unit 4 (Direct House), Quayside Business Park,
| George Mann Road, Leeds, LS10 1DJ, United Kingdom
Single Registration Number (SRN): | GB-MF-000033926
Basic UDI-DI: | 506072613GMN004X2
Global Medical Device
Nomenclature Code: | 36534
European Medical Device
Nomenclature Code: | Y061899
Applicable Legislations And
Standards: | As per Appendix I - Applicable Legislations and Standards
Configurations And Variants: | As per Appendix II - Product Listing/Schedule
Intended Purpose: | The COVVI Power Supply is intended to power externally controlled upper limb
| prosthetic hands.
Medical Device Classification: | Class 1 [Rule 13]
Notified Body: | N/A
CE Certificate: | N/A
EU Authorised Representative: | Advena Limited, Tower Business Centre, 2nd Flr.,
| Tower Street, Swatar, BKR 4013, Malta
EU Authorised Representative
SRN: | MT-AR-000000234
Medical Device Regulation Assessment Route: | In conformity with Annexes II and III, the Declaration of Conformity has been drawn
| up in accordance with Article 19 of Regulation (EU) 2017/745.

Full Declaration of Conformity Document
Please click the following link to view the full COVVI Power Supply Declaration of Conformity (EU): www.covvi.com/wp-content/uploads/documents/DoC/Declaration-Of-Conformity-EU-COVVI-Power-Supply.pdf www.covvi.com | Unit 4, Quayside Business Park, Leeds, LS10 1DJ | +44 (0)20 3949 9500 | Page 64

## 16.0 Declaration of Conformity

Declaration of Conformity for:
The Glove Kit (UK, UKCA Marking)

We hereby declare, under the manufacturer’s sole responsibility, that the products described in this document are in conformity with the applicable provisions of the Medical Devices Regulations 2002 (SI 2002 No. 618, as amended), and are manufactured and released in accordance with the Quality Management System in force on the date of issue of this declaration. The UKCA marking may be affixed.

Full Declaration of Conformity Document
Please click the following link to view the full Glove Kit Declaration of Conformity (UK): www.covvi.com/wp-content/uploads/documents/DoC/Declaration-Of-Conformity-UK-COVVI-Glove-Kit.pdf
Product Name: | Glove Kit
Legal Manufacturer: | COVVI Ltd., Unit 4 (Direct House), Quayside Business Park,
| George Mann Road, Leeds, LS10 1DJ, United Kingdom
EU Single Registration Number
(SRN): | GB-MF-000033926
Basic UDI-DI: | 506072613GMN1GK2Q
Global Medical Device
Nomenclature Code: | 64736
Applicable Legislations And
Standards: | As per Appendix I - Applicable Legislations and Standards
Configurations And Variants: | As per Appendix II - Product Listing/Schedule
Intended Purpose: | The COVVI Glove Kit is an accessory intended to be worn with the COVVI Hand to
| protect it from external contaminants and maintain device integrity.
Medical Device Classification: | Class 1 [Rule 1]
Notified Body: | N/A
UKCA Certificate: | N/A
UK Approved Body Name: | Not Applicable for Class I
UK Approved Body Identification
Number: | Not Applicable for Class I
Medical Device Regulation Assessment Route: | In conformity with the applicable requirements of the Medical Devices Regulations
| 2002 (SI 2002 No. 618, as amended), commonly referred to as UK MDR 2002.

www.covvi.com | Unit 4, Quayside Business Park, Leeds, LS10 1DJ | +44 (0)20 3949 9500 | Page 65

## 16.0 Declaration of Conformity

Declaration of Conformity for:
The Glove Kit (EU, CE Marking)

We herewith declare, under the manufacturer’s sole responsibility, that the products described in this document are in conformity with the relevant requirements of Regulation (EU) 2017/745 of the European Parliament and of the Council of 5 April 2017 concerning Medical Devices and are manufactured and released according to the provision of the quality management system in force on the date of issue of this declaration and the CE Mark may be affixed.

Product Name: | Glove Kit
Legal Manufacturer: | COVVI Ltd., Unit 4 (Direct House), Quayside Business Park,
| George Mann Road, Leeds, LS10 1DJ, United Kingdom
Single Registration Number (SRN): | GB-MF-000033926
Basic UDI-DI: | 506072613GMN1GK2Q
Global Medical Device
Nomenclature Code: | 64736
European Medical Device
Nomenclature Code: | Y090312
Applicable Legislations And
Standards: | As per Appendix I - Applicable Legislations and Standards
Configurations And Variants: | As per Appendix II - Product Listing/Schedule
Intended Purpose: | The COVVI Glove Kit is an accessory intended to be worn with the COVVI Hand to
| protect it from external contaminants and maintain device integrity.
Medical Device Classification: | Class 1 [Rule 1]
Notified Body: | N/A
CE Certificate: | N/A
EU Authorised Representative: | Advena Limited, Tower Business Centre, 2nd Flr.,
| Tower Street, Swatar, BKR 4013, Malta
EU Authorised Representative
SRN: | MT-AR-000000234
Medical Device Regulation Assessment Route: | In conformity with Annexes II and III, the Declaration of Conformity has been drawn
| up in accordance with Article 19 of Regulation (EU) 2017/745.

Full Declaration of Conformity Document
Please click the following link to view the full Glove Kit Declaration of Conformity (EU): www.covvi.com/wp-content/uploads/documents/DoC/Declaration-Of-Conformity-EU-COVVI-Glove-Kit.pdf www.covvi.com | Unit 4, Quayside Business Park, Leeds, LS10 1DJ | +44 (0)20 3949 9500 | Page 66

## 16.0 Declaration of Conformity

Declaration of Conformity for:
The COVVI Go (UK, UKCA Marking)

We hereby declare, under the manufacturer’s sole responsibility, that the products described in this document are in conformity with the applicable provisions of the Medical Devices Regulations 2002 (SI 2002 No. 618, as amended), and are manufactured and released in accordance with the Quality Management System in force on the date of issue of this declaration. The UKCA marking may be affixed.

Full Declaration of Conformity Document
Please click the following link to view the full COVVI Go Declaration of Conformity (UK): www.covvi.com/wp-content/uploads/documents/DoC/Declaration-Of-Conformity-UK-COVVI-Go-App.pdf
Product Name: | COVVI Go
Legal Manufacturer: | COVVI Ltd., Unit 4 (Direct House), Quayside Business Park,
| George Mann Road, Leeds, LS10 1DJ, United Kingdom
EU Single Registration Number
(SRN): | GB-MF-000033926
Basic UDI-DI: | 506072613GMN012WZ
Global Medical Device
Nomenclature Code: | 64734
Applicable Legislations And
Standards: | As per Appendix I - Applicable Legislations and Standards
Configurations And Variants: | As per Appendix II - Product Listing/Schedule
Intended Purpose: | The COVVI Go is software intended to assist users of the COVVI Hand by enabling
| the selection and customization of grip functions and the adjustment of control
| settings.
Medical Device Classification: | Class 1 [Rule 12]
Notified Body: | N/A
UKCA Certificate: | N/A
UK Approved Body Name: | Not Applicable for Class I
UK Approved Body Identification
Number: | Not Applicable for Class I
Medical Device Regulation Assessment Route: | In conformity with the applicable requirements of the Medical Devices Regulations
| 2002 (SI 2002 No. 618, as amended), commonly referred to as UK MDR 2002.

www.covvi.com | Unit 4, Quayside Business Park, Leeds, LS10 1DJ | +44 (0)20 3949 9500 | Page 67

## 16.0 Declaration of Conformity

Declaration of Conformity for:
The COVVI Go (EU, CE Marking)

We herewith declare, under the manufacturer’s sole responsibility, that the products described in this document are in conformity with the relevant requirements of Regulation (EU) 2017/745 of the European Parliament and of the Council of 5 April 2017 concerning Medical Devices and are manufactured and released according to the provision of the quality management system in force on the date of issue of this declaration and the CE Mark may be affixed.

Product Name: | COVVI Go
Legal Manufacturer: | COVVI Ltd., Unit 4 (Direct House), Quayside Business Park,
| George Mann Road, Leeds, LS10 1DJ, United Kingdom
Single Registration Number (SRN): | GB-MF-000033926
Basic UDI-DI: | 506072613GMN012WZ
Global Medical Device
Nomenclature Code: | 64734
European Medical Device
Nomenclature Code: | Z129082
Applicable Legislations And
Standards: | As per Appendix I - Applicable Legislations and Standards
Configurations And Variants: | As per Appendix II - Product Listing/Schedule
Intended Purpose: | The COVVI Go is software intended to assist users of the COVVI Hand by enabling
| the selection and customization of grip functions and the adjustment of control
| settings.
Medical Device Classification: | Class 1 [Rule 13]
Notified Body: | N/A
CE Certificate: | N/A
EU Authorised Representative: | Advena Limited, Tower Business Centre, 2nd Flr.,
| Tower Street, Swatar, BKR 4013, Malta
EU Authorised Representative
SRN: | MT-AR-000000234
Medical Device Regulation Assessment Route: | In conformity with Annexes II and III, the Declaration of Conformity has been drawn
| up in accordance with Article 19 of Regulation (EU) 2017/745.

Full Declaration of Conformity Document
Please click the following link to view the full COVVI Go Declaration of Conformity (EU): www.covvi.com/wp-content/uploads/documents/DoC/Declaration-Of-Conformity-EU-COVVI-Go-App.pdf www.covvi.com | Unit 4, Quayside Business Park, Leeds, LS10 1DJ | +44 (0)20 3949 9500 | Page 68

## 16.0 Declaration of Conformity

Declaration of Conformity for:
The COVVI Hand - Straight Wrist (UK, UKCA Marking)

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

Full Declaration of Conformity Document
Please click the following link to view the full COVVI Hand - Straight Wrist Declaration of Conformity (UK): www.covvi.com/wp-content/uploads/documents/DoC/Declaration-Of-Conformity-UK-COVVI-Hand-Straight-Wrist.pdf
Product Name: | COVVI Hand - Straight Wrist
Legal Manufacturer: | COVVI Ltd., Unit 4 (Direct House), Quayside Business Park,
| George Mann Road, Leeds, LS10 1DJ, United Kingdom
EU Single Registration Number
(SRN): | GB-MF-000033926
Basic UDI-DI: | 506072613GMN027XE
Global Medical Device
Nomenclature Code: | 41497
Applicable Legislations And
Standards: | As per Appendix I - Applicable Legislations and Standards
Configurations And Variants: | As per Appendix II - Product Listing/Schedule
Intended Purpose: | The COVVI Hand - Straight Wrist is an external, motor-driven prosthetic hand with
| a Straight Wrist designed to assist individuals with unilateral or bilateral upper
| limb deficiencies. Specifically crafted with anatomically correct dimensions, the
| COVVI Hand - Straight Wrist facilitates activities of daily living through controlled
| movement of programmed grip patterns.
Medical Device Classification: | Class 1 [Rule 12]
Notified Body: | N/A
UKCA Certificate: | N/A
UK Approved Body Name: | Not Applicable for Class I
UK Approved Body Identification
Number: | Not Applicable for Class I
Medical Device Regulation Assessment Route: | In conformity with the applicable requirements of the Medical Devices Regulations
| 2002 (SI 2002 No. 618, as amended), commonly referred to as UK MDR 2002.

www.covvi.com | Unit 4, Quayside Business Park, Leeds, LS10 1DJ | +44 (0)20 3949 9500 | Page 69
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

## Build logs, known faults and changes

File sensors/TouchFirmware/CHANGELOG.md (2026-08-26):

# Firmware do sensor tátil 5×5 + HX711 — correções da cadeia USB

Ponto de partida: a versão que rodava na bancada em 14/08/2026. O protocolo de
linha (`ADC,…`, `RA,…`, `SA,…`, `CN_*`, `FORCE,…`) e toda a lógica neural
(Izhikevich, template sináptico, cuneiformes) estão **inalterados** — o
`touch_pack/touch_source.py` continua valendo sem mudança.

A evidência que motivou a revisão já existia no lado do PC:
`touch_source.py:344` mantém um contador `frames_bad` com o comentário *"Frame
truncado — o firmware perdeu bytes na saída"*. Esse contador existe porque
dispara.

## O orçamento de dados

Relógio: HSE 8 MHz → PLL(M=8, N=336, P=2) → **168 MHz**. APB1 = 42 MHz, clock
dos timers = 84 MHz. TIM6 com prescaler 83 → 1 MHz; período 199 → trigger a
cada **200 µs**. Cada trigger converte as 5 colunas → ISR a 5 kHz → um frame
5×5 completo a cada **1 ms**.

| Fonte | Taxa | Bytes/linha | Vazão |
| --- | --- | --- | --- |
| `ADC,…` | 1000/s | ~143 | **~143 KB/s** |
| `CN_MM/RA/SA` | até 3000/s | ~18 | até ~54 KB/s |
| `FORCE,…` | 100/s | ~35 | ~3,5 KB/s |

Contra isso, o dreno enviava no máximo 64 bytes por transferência, uma de cada
vez.

---

## [1] `packet[]` sobrescrito com a transferência em voo — corrupção

**O defeito principal.** `CDC_Transmit_FS` apenas guarda o ponteiro
(`USBD_CDC_SetTxBuffer`) e retorna; no OTG_FS do F7 os bytes só são empurrados
para a FIFO depois, dentro da interrupção. O buffer precisa ficar intacto até
`TxState` voltar a zero.

A versão antiga enchia `packet` **antes** de saber se podia transmitir:

```c
while (temp_tail != usb_head && len < USB_PACKET_SIZE)
    packet[len++] = usb_tx_buffer[temp_tail];   // escreve primeiro
...
if (CDC_Transmit_FS(packet, len) == USBD_OK)    // pergunta depois
    usb_tail = temp_tail;
```

Como `usb_tail` já havia avançado na chamada bem-sucedida anterior, a iteração
seguinte do laço principal sobrescrevia `packet` com os bytes **seguintes**
enquanto a transferência anterior ainda o estava lendo. O host recebia as duas
metades misturadas. Em seguida `CDC_Transmit_FS` devolvia `USBD_BUSY`,
`usb_tail` não avançava, e os mesmos bytes eram reenviados — **corrompidos e
duplicados**.

**Correção:** `usb_tx_ready()` (que consulta `hcdc->TxState`) é chamado
*antes* de tocar em `packet`.

## [2] Ring buffer sem seção crítica

`usb_buffer_write` tem dois produtores concorrentes:

| Contexto | Chamadas |
| --- | --- |
| ISR (`DMA2_Stream0` → `HAL_ADC_ConvCpltCallback` → `update_taxels`) | `send_adc_frame`, `CN_*` |
| laço principal | `process_spikes`, `FORCE`, boot, `STAT` |

O par `usb_tx_buffer[usb_head] = c; usb_head = next;` não é atômico: uma ISR
caindo entre as duas instruções escrevia no mesmo índice e tinha o seu byte
sobrescrito — caracteres de uma linha apareciam no meio de outra.

**Correção:** `irq_save()`/`irq_restore()`, que preservam o `PRIMASK` do
chamador em vez de chamar `__enable_irq()` cego. Isso importa porque a leitura
do HX711 também usa seção crítica; a versão antiga reabilitaria as
interrupções ao sair da região interna.

## [3] Escrita all-or-nothing

A versão antiga copiava byte a byte e dava `break` ao encher, **cortando a
linha no meio**. Agora a mensagem só entra se couber inteira; se não couber é
descartada por completo e contabilizada. Frame que chega, chega íntegro.

## [4] Chunk de transmissão: 64 → 512 B

`USB_PACKET_SIZE` (64) é o *wMaxPacketSize* do endpoint bulk em Full Speed —
não é o teto de uma **transferência**. `CDC_Transmit_FS` aceita centenas de
bytes e a própria pilha os fatia em pacotes de 64. Usar 64 como tamanho de
transferência limitava a vazão a ~1 transferência por polling do host.

Novo `USB_TX_CHUNK = 512` (8 pacotes por transferência) e ring de 8192 B.
Transferências múltiplas de 64 são encurtadas em 1 byte para dispensar o
pacote de comprimento zero (ZLP) que fecharia a transferência.

## [5] Descarte deixou de ser mudo

Nova linha periódica `STAT,drop=<n>,t=<us>` (1 Hz, `USB_STAT_PERIOD_MS`).
Antes, uma perda no firmware e uma perda no link eram indistinguíveis do lado
do PC. `touch_source.py` ignora prefixos desconhecidos, então a linha é
inofensiva para quem não a consome.

## [6] HX711: temporização do PD_SCK

Datasheet: nível alto tem mínimo de **0,2 µs** (T2) e **máximo de 60 µs** —
acima disso o chip entra em power-down. Dois `HAL_GPIO_WritePin` consecutivos
a 168 MHz davam ~40 ns, **abaixo do mínimo**: leituras podiam sair com bits
errados.

Além disso, os 25 pulsos rodavam dentro de **um único** `__disable_irq()`,
bloqueando a ISR do ADC de 5 kHz. Deixá-los completamente livres também não
serve: uma ISR longa (o `update_taxels` chega a montar linhas) seguraria o SCK
alto por mais de 60 µs.

**Correção:** `hx711_pulse()` — atraso por contador de ciclos do DWT (60
ciclos ≈ 0,36 µs) e janela sem interrupção **por pulso**, não por leitura.

## [7] HX711: gate de amostragem truncado

`(uint32_t)(1000.0f / 80.0f)` = **12**, não 12,5 → amostragem real a 83,3 Hz
enquanto o `hx711_alpha` do IIR era calculado para 80 Hz. Quem dita a cadência
é o próprio HX711 (~80 SPS pelo pino RATE); o gate por milissegundo foi
removido e a leitura passou a acontecer quando `HX711_IsReady()` avisa.

`HX711_ReadAverage` tinha o mesmo tipo de erro — o laço gastava a iteração sem
ler quando o chip não estava pronto, então pedir 200 amostras rendia bem menos
e a tara saía de uma média mais pobre que a pedida. A função foi substituída
pela máquina de estados de `[12]`, que conta amostras de verdade.

## [8] Timestamp de 32 bits dava a volta a cada 71,6 min

TIM2 conta a 1 MHz num registrador de 32 bits → volta em 4294,97 s. Gravações
longas viam o tempo voltar a zero. `micros64()` estende para 64 bits por
software (chamado a cada frame, muito acima da taxa mínima de uma vez por
volta). O valor continua sendo microssegundos decimais, então os regex
`t=(\d+)` do PC seguem casando.

**Fica DESLIGADO por padrão (`TS_64BIT 0`).** `touch_pack_msgs/msg/TouchFrame.msg`
declara `uint32 t_us`, e a GUI republica cada frame ADC nesse campo. O rclpy
rejeita valor acima de `2^32-1` com `AssertionError` — que
`palpation_gui._publish_tactile_line` **não captura** (ela trata só
`ValueError`/`IndexError`). Ligar isto faria a republicação em ROS morrer
depois de 71,6 min de uptime do MCU: quebra silenciosa e tardia, pior que o
wraparound que se queria consertar. Verificado na bancada — a atribuição de
`4294967396` levanta a exceção.

O parser de texto (`touch_source.py`) aceita o valor largo sem mudança; quem
não aceita é a mensagem ROS. Para ligar, nesta ordem: alargar `t_us` para
`uint64` no `.msg`, reconstruir `touch_pack_msgs`, conferir os consumidores de
`touch_t_us` no `palpation_logger`, e só então trocar para 1.

## [9] `snprintf` de 25 inteiros dentro da ISR

`send_adc_frame` rodava a 1 kHz **dentro da ISR do ADC**, que dispara a cada
200 µs. Substituído por um formatador decimal direto; a saída é byte-a-byte
idêntica (há teste comparando com o `snprintf` original).

## [10] Retorno de `snprintf` não clampeado

`snprintf` devolve o tamanho que a string **teria**, que pode passar do
buffer. Esse valor ia direto para `memcpy`/`usb_buffer_write`, lendo além do
array. `snprintf_len()` clampa. `process_spikes` também passou a verificar
`batch_count` antes do `memcpy` — a versão antiga nunca comparava com o
tamanho de `batch_msg`.

## [11] `dwt_delay_cycles` podia travar para sempre — **regressão minha**

Introduzido pela correção `[6]` e corrigido depois de uma sessão de
diagnóstico na bancada. Sintoma: **o dispositivo enumera e não envia um byte
sequer, nem o banner de boot.**

O contador de ciclos do DWT não liga sozinho. No Cortex-M7 o bloco é CoreSight
e tem *Lock Access Register*: sem escrever `0xC5ACCE55` em `DWT->LAR`, as
escritas em `DWT->CTRL` são **ignoradas** e `CYCCNT` fica em zero. Com o
contador parado,

```c
while ((DWT->CYCCNT - start) < cycles) { __NOP(); }
```

nunca termina. Esse atraso é chamado por `hx711_pulse()`, que roda na tara,
que rodava no boot **antes** do laço principal. Resultado: o firmware travava
antes de transmitir qualquer coisa, enquanto o USB seguia enumerando — porque
enumeração é interrupção e não depende do laço.

Três defesas, e nenhuma sozinha bastava:

1. escrever a chave no LAR antes de habilitar o `CYCCNT`;
2. **verificar** que o contador anda, e cair num laço de reserva por `NOP`
   quando não anda;
3. teto de iterações no caminho do DWT, para o caso de o contador congelar no
   meio (depurador anexado).

## [12] O boot bloqueava no HX711 antes de o USB falar

O defeito estrutural que tornou `[11]` tão difícil de diagnosticar — e que
existia desde a versão original.

A tara rodava **antes** do `while(1)`, somando 200 leituras de uma vez.
Enquanto durava, `usb_buffer_process()` não era chamado: o banner de boot
ficava no buffer sem sair. Se a célula não respondesse, o mudo durava toda a
janela de espera; se algo lá dentro travasse, o mudo era permanente. Do lado
do PC os três casos — placa morta, célula ausente, firmware travado — são
**indistinguíveis**.

Agora a tara é uma máquina de estados no laço (`HX711_TareStep`): uma amostra
por volta, só quando o chip avisa, com desistência por tempo
(`HX711_TARE_WINDOW_MS`) que reporta `HX711 TARE TIMEOUT,<obtidas>,<pedidas>`.
O USB fala desde o primeiro milissegundo, aconteça o que acontecer com a
célula — inclusive ela não estar conectada.

`HX711_Read` também passou a ter timeout em **tempo** (`HAL_GetTick`), não em
contagem de iterações: o teto antigo de 1.000.000 de voltas valia uma duração
diferente conforme o clock, e ninguém sabia dizer qual.

**Regra que vale para o futuro:** nada entre o `MX_USB_DEVICE_Init()` e o
`while(1)` pode bloquear. Um dispositivo que não consegue falar não consegue
ser diagnosticado.

---

## NÃO corrigido, de propósito

### `select_row()` ignora o parâmetro `row`

```c
void select_row(uint8_t row) {   // `row` nunca é lido
    ... escreve row_mask ...
    row_mask = row5(row_mask);   // roda uma máscara estática
}
```

A máscara escrita e o `row_idx` usado para indexar `taxels[]` avançam de forma
independente. Traçando o boot: `row_mask` começa em `0b11110` (linha 0);
`select_row(0)` no `main` escreve essa máscara e roda para `0b11101`; a
primeira ISR chama `select_row(0)` e escreve `0b11101` — **linha 1** — mas
guarda os dados como linha 0.

Amarrar a máscara a `row` mudaria qual taxel físico responde por cada índice
do frame 5×5, invalidando a calibração e todas as gravações existentes. É uma
correção de bancada, com o sensor na mão e um estímulo conhecido, não de
escrivaninha. `row_masks[ROWS]` está declarado e nunca usado — provavelmente
era esta a intenção original.

### Variáveis mortas

`hx711_ready`, `grams`, `last_force_time`, `taxels[].I`, `I_inh` global
(sombreado por um local), `g_syn_RA`/`g_syn_SA` e `I_inh_buffer`/`I_inh_index`
não são lidos. Não são defeitos e removê-los alargaria o diff sem necessidade.

### Vazão residual

Mesmo com o chunk de 512 B, ~143 KB/s de ASCII sobre CDC FS é exigente. Se o
`STAT,drop=` continuar subindo, as saídas em ordem de custo são: reduzir a
taxa de frames ADC, ou trocar a linha ASCII por binário (25×`uint16` + tempo
≈ 58 B contra ~143 B) — esta última exige mudar o parser do PC junto.

---

## Testes

```
cd sensors/TouchFirmware
make check    # sintaxe, -Wall -Wextra, zero avisos
make test     # 13 grupos contra stubs da HAL em test/stub/
```

Cobrem: formatadores decimais (incluindo `UINT64_MAX`), igualdade byte-a-byte
do frame ADC com o `snprintf` original, escrita all-or-nothing e o contador de
descarte, ausência de escrita em `packet[]` com transferência em voo, ausência
de transferências múltiplas de 64, wraparound do ring, monotonicidade do
timestamp através de duas voltas do TIM2, clamp do `snprintf`, preservação dos
dados enquanto o CDC não está configurado, **terminação do atraso do HX711 nos
três estados possíveis do `CYCCNT`** (parado, normal, congelado no meio) e
**desistência da tara sem célula conectada**.

**Não substituem a bancada.** Timing do HX711, comportamento real do endpoint
USB e a taxa de frames medida pelo PC só se verificam com o hardware ligado —
o número a acompanhar é `frames_ok` vs `frames_bad` no `touch_source.py`, ao
lado do `STAT,drop=`.

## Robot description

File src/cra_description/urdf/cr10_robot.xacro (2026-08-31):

<?xml version="1.0"?>
<robot name="cr10_robot" xmlns:xacro="http://ros.org/wiki/xacro">

  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

  <link name="dummy_link"/>

  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
  <link name="base_link">
    <inertial>
      <origin xyz="-0.0017435 -4.7141E-06 0.032774" rpy="0 0 0" />
      <mass value="1.8265" />
      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
    </inertial>
    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
  </link>

  <link name="world"/>
  <joint name="world_joint" type="fixed">
    <origin xyz="0 0 0.03" rpy="0 0 0" />
    <parent link="world" />
    <child link="dummy_link" />
  </joint>
  <joint name="dummy_joint" type="fixed">
    <parent link="dummy_link" />
    <child link="base_link" />
  </joint>

  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
  <link name="Link1">
    <inertial>
      <origin xyz="-1.6635E-06 -0.010819 0.0028389" rpy="0 0 0" />
      <mass value="4.1649" />
      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
    </inertial>
    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
  </link>
  <joint name="joint1" type="revolute">
    <origin xyz="0 0 0.1765" rpy="0 0 0" />
    <parent link="base_link" />
    <child link="Link1" />
    <axis xyz="0 0 -1" />
    <limit lower="-6.27" upper="6.27" effort="300" velocity="100" />
  </joint>

  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
  <link name="ring_j1">
    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
  </link>
  <joint name="joint_ring_j1" type="fixed">
    <origin xyz="0 0 -0.0830" rpy="0 0 0"/>
    <parent link="Link1"/>
    <child link="ring_j1"/>
  </joint>
  <link name="cap_j1">
    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
  </link>
  <joint name="joint_cap_j1" type="fixed">
    <origin xyz="0 0 -0.0760" rpy="0 0 0"/>
    <parent link="Link1"/>
    <child link="cap_j1"/>
  </joint>

  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
  <link name="ring_j2">
    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
  </link>
  <joint name="joint_ring_j2" type="fixed">
    <origin xyz="0 0 0.0870" rpy="0 0 0"/>
    <parent link="Link1"/>
    <child link="ring_j2"/>
  </joint>
  <link name="cap_j2">
    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
  </link>
  <joint name="joint_cap_j2" type="fixed">
    <origin xyz="0 0 0.0810" rpy="0 0 0"/>
    <parent link="Link1"/>
    <child link="cap_j2"/>
  </joint>

  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
  <link name="Link2">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
    <inertial>
      <origin xyz="-0.24631 3.5816E-07 0.19515" rpy="0 0 0" />
      <mass value="11.314" />
      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
    </inertial>
    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
  </link>
  <joint name="joint2" type="revolute">
    <origin xyz="0 0 0" rpy="1.5708 1.5708 0" />
    <parent link="Link1" />
    <child link="Link2" />
    <axis xyz="0 0 1" />
    <limit lower="-6.27" upper="6.27" effort="300" velocity="100" />
  </joint>

  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
  <link name="ring_j3">
    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
  </link>
  <joint name="joint_ring_j3" type="fixed">
    <origin xyz="-0.5550 0 0.1930" rpy="0 0 0"/>
    <parent link="Link2"/>
    <child link="ring_j3"/>
  </joint>
  <link name="cap_j3">
    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
  </link>
  <joint name="joint_cap_j3" type="fixed">
    <origin xyz="-0.5490 0 0.1930" rpy="0 0 0"/>
    <parent link="Link2"/>
    <child link="cap_j3"/>
  </joint>

  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
  <link name="Link3">
    <inertial>
      <origin xyz="-0.270855859955203 2.5144690851208E-07 0.0622960395387155" rpy="0 0 0" />
      <mass value="4.89191189064363" />
      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
    </inertial>
    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
  </link>
  <joint name="joint3" type="revolute">
    <origin xyz="-0.607 0 0" rpy="0 0 0" />
    <parent link="Link2" />
    <child link="Link3" />
    <axis xyz="0 0 1" />
    <limit lower="-2.861" upper="2.861" effort="300" velocity="100" />
  </joint>

  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
  <link name="Link4">
    <inertial>
      <origin xyz="-2.53137491438456E-07 0.00798724498566683 -0.00589074229668524" rpy="0 0 0" />
      <mass value="1.16884294495796" />
      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
    </inertial>
    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
  </link>
  <joint name="joint4" type="revolute">
    <origin xyz="-0.568 0 0.191" rpy="0 0 -1.5708" />
    <parent link="Link3" />
    <child link="Link4" />
    <axis xyz="0 0 1" />
    <limit lower="-6.27" upper="6.27" effort="300" velocity="100" />
  </joint>

  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
  <link name="ring_j4">
    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
  </link>
  <joint name="joint_ring_j4" type="fixed">
    <origin xyz="0 0 -0.0600" rpy="0 0 0"/>
    <parent link="Link4"/>
    <child link="ring_j4"/>
  </joint>
  <link name="cap_j4">
    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
  </link>
  <joint name="joint_cap_j4" type="fixed">
    <origin xyz="0 0 -0.0530" rpy="0 0 0"/>
    <parent link="Link4"/>
    <child link="cap_j4"/>
  </joint>

  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
  <link name="Link5">
    <inertial>
      <origin xyz="5.50699455951951E-07 -0.0145467578029201 -0.00454887087411437" rpy="0 0 0" />
      <mass value="1.22303084244711" />
      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
    </inertial>
    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
  </link>
  <joint name="joint5" type="revolute">
    <origin xyz="0 -0.125 0" rpy="1.5708 0 0" />
    <parent link="Link4" />
    <child link="Link5" />
    <axis xyz="0 0 1" />
    <limit lower="-6.27" upper="6.27" effort="300" velocity="100" />
  </joint>

  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
  <link name="ring_j5">
    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
  </link>
  <joint name="joint_ring_j5" type="fixed">
    <origin xyz="0 0 -0.0570" rpy="0 0 0"/>
    <parent link="Link5"/>
    <child link="ring_j5"/>
  </joint>
  <link name="cap_j5">
    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
  </link>
  <joint name="joint_cap_j5" type="fixed">
    <origin xyz="0 0 -0.0500" rpy="0 0 0"/>
    <parent link="Link5"/>
    <child link="cap_j5"/>
  </joint>

  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
  <link name="Link6">
    <inertial>
      <origin xyz="1.42987471244488E-10 2.29640694859867E-05 -0.0205297780389956" rpy="0 0 0" />
      <mass value="0.205439548775225" />
      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
    </inertial>
    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
  </link>
  <joint name="joint6" type="revolute">
    <origin xyz="0 0.1084 0" rpy="-1.5708 0 0" />
    <parent link="Link5" />
    <child link="Link6" />
    <axis xyz="0 0 1" />
    <limit lower="-6.27" upper="6.27" effort="300" velocity="100" />
  </joint>

  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
  <link name="ring_j6">
    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
  </link>
  <joint name="joint_ring_j6" type="fixed">
    <origin xyz="0 0 -0.0300" rpy="0 0 0"/>
    <parent link="Link6"/>
    <child link="ring_j6"/>
  </joint>
  <link name="cap_j6">
    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
  </link>
  <joint name="joint_cap_j6" type="fixed">
    <origin xyz="0 0 -0.0230" rpy="0 0 0"/>
    <parent link="Link6"/>
    <child link="cap_j6"/>
  </joint>

  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
  <ros2_control name="GazeboSystem" type="system">
    <hardware>
      <plugin>gazebo_ros2_control/GazeboSystem</plugin>
    </hardware>
    <joint name="joint1">
      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
      <command_interface name="position"/>
      <state_interface name="position">
        <param name="initial_value">-0.7854</param>
      </state_interface>
      <state_interface name="velocity"/>
    </joint>
    <joint name="joint2">
      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
      <command_interface name="position"/>
      <state_interface name="position">
        <param name="initial_value">0.5236</param>
      </state_interface>
      <state_interface name="velocity"/>
    </joint>
    <joint name="joint3">
      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
      <command_interface name="position"/>
      <state_interface name="position">
        <param name="initial_value">-2.0944</param>
      </state_interface>
      <state_interface name="velocity"/>
    </joint>
    <joint name="joint4">
      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
      <command_interface name="position"/>
      <state_interface name="position">
        <param name="initial_value">0.0</param>
      </state_interface>
      <state_interface name="velocity"/>
    </joint>
    <joint name="joint5">
      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
      <command_interface name="position"/>
      <state_interface name="position">
        <param name="initial_value">1.5708</param>
      </state_interface>
      <state_interface name="velocity"/>
    </joint>
    <joint name="joint6">
      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
      <command_interface name="position"/>
      <state_interface name="position">
        <param name="initial_value">0.0</param>
      </state_interface>
      <state_interface name="velocity"/>
    </joint>
  </ros2_control>

  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

</robot>

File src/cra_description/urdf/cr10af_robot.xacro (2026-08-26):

<?xml version="1.0"?>
<robot name="cr10af_robot" xmlns:xacro="http://ros.org/wiki/xacro">
  <link name="dummy_link"/>
  <link name="base_link">
    <inertial>
      <origin xyz="-3.7612E-06 0.0011357 0.032382" rpy="0 0 0" />
      <mass value="2.01" />
      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
    </inertial>
    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
  </link>
    <link name="world"/>
<joint name="world_joint" type="fixed">
    <origin xyz="0 0 0.03" rpy="0 0 0" />
    <parent link="world" />
    <child link="dummy_link" />
  </joint>
  <joint name="dummy_joint" type="fixed">
      <parent link="dummy_link" />
      <child link="base_link" />
    </joint>
  <link name="J1">
    <inertial>
      <origin xyz="-5.9674E-07 -0.011961 0.10128" rpy="0 0 0" />
      <mass value="8.97" />
      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
    </inertial>
    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
  </link>
  <joint name="joint1" type="revolute">
    <origin xyz="0 0 0.079" rpy="0 0 0" />
    <parent link="base_link" />
    <child link="J1" />
    <axis xyz="0 0 1" />
    <limit lower="-6.2831" upper="6.2831" effort="0" velocity="0" />
  </joint>
  <link name="J2">
    <inertial>
      <origin xyz="2.1881E-07 -0.093266 0.24604" rpy="0 0 0" />
      <mass value="16.9" />
      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
    </inertial>
    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
  </link>
  <joint name="joint2" type="revolute">
    <origin xyz="0 -0.102 0.0975" rpy="0 0 0" />
    <parent link="J1" />
    <child link="J2" />
    <axis xyz="0 -1 0" />
    <limit lower="-6.2831" upper="6.2831" effort="0" velocity="0" />
  </joint>
  <link name="J3">
    <inertial>
      <origin xyz="-9.4859E-08 0.05571 0.27104" rpy="0 0 0" />
      <mass value="5.47" />
      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
    </inertial>
    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
  </link>
  <joint name="joint3" type="revolute">
    <origin xyz="0 -0.015 0.607" rpy="0 0 0" />
    <parent link="J2" />
    <child link="J3" />
    <axis xyz="0 1 0" />
    <limit lower="-2.7925" upper="2.7925" effort="0" velocity="0" />
  </joint>
  <link name="J4">
    <inertial>
      <origin xyz="2.8401E-07 -0.060432 -0.010119" rpy="0 0 0" />
      <mass value="2.6" />
      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
    </inertial>
    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
  </link>
  <joint name="joint4" type="revolute">
    <origin xyz="0 -0.0075 0.568" rpy="0 0 0" />
    <parent link="J3" />
    <child link="J4" />
    <axis xyz="0 -1 0" />
    <limit lower="-6.2831" upper="6.2831" effort="0" velocity="0" />
  </joint>
  <link name="J5">
    <inertial>
      <origin xyz="-5.8252E-07 0.016958 0.053728" rpy="0 0 0" />
      <mass value="2.6" />
      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
    </inertial>
    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
  </link>
  <joint name="joint5" type="revolute">
    <origin xyz="0 -0.066501 0.068" rpy="0 0 0" />
    <parent link="J4" />
    <child link="J5" />
    <axis xyz="0 0 1" />
    <limit lower="-6.2831" upper="6.2831" effort="0" velocity="0" />
  </joint>
  <link name="J6">
    <inertial>
      <origin xyz="7.3738E-09 -0.028312 6.3267E-05" rpy="0 0 0" />
      <mass value="0.4" />
      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
    </inertial>
    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
  </link>
  <joint name="joint6" type="revolute">
    <origin xyz="0 -0.066499 0.057" rpy="0 0 0" />
    <parent link="J5" />
    <child link="J6" />
    <axis xyz="0 -1 0" />
    <limit lower="-6.2831" upper="6.2831" effort="0" velocity="0" />
  </joint>
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
    <ros2_control name="GazeboSystem" type="system">
        <hardware>
            <plugin>gazebo_ros2_control/GazeboSystem</plugin>
        </hardware>
        <joint name="joint1">
            <command_interface name="position">
                <param name="min">-1</param>
                <param name="max">1</param>
            </command_interface>
            <state_interface name="position">
                <param name="initial_value">0.0</param>
            </state_interface>
            <state_interface name="velocity"/>
        </joint>
        <joint name="joint2">
            <command_interface name="position">
                <param name="min">-1</param>
                <param name="max">1</param>
            </command_interface>
            <state_interface name="position">
                <param name="initial_value">0.0</param>
            </state_interface>
            <state_interface name="velocity"/>
        </joint>
        <joint name="joint3">
            <command_interface name="position">
                <param name="min">-1</param>
                <param name="max">1</param>
            </command_interface>
            <state_interface name="position">
                <param name="initial_value">0.0</param>
            </state_interface>
            <state_interface name="velocity"/>
        </joint>
        <joint name="joint4">
            <command_interface name="position">
                <param name="min">-1</param>
                <param name="max">1</param>
            </command_interface>
            <state_interface name="position">
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

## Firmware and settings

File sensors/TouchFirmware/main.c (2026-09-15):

#include "stm32f7xx_hal.h"
#include "usb_device.h"
#include "usbd_cdc_if.h"
#include <math.h>
#include <stdio.h>
#include <string.h>
#include <stdbool.h>
#include <stdint.h>

// DEFINIÇÕES
#define DEBUG_ADC_PORT GPIOB
#define DEBUG_ADC_PIN  GPIO_PIN_8 //(GPIO DE PULSO PRA ADC)
#define DEBUG_IZH_PORT GPIOB
#define DEBUG_IZH_PIN  GPIO_PIN_9//(GPIO DE PULSO PRA Izhikevich)

//////////////////////////////////////////////
#define ROWS 5
#define COLS 5
#define NUM_TAXELS (ROWS*COLS)
#define DIFF_BUFFER 25
static uint8_t row_mask = 0x1E;

// IZH PARAMETERS

/* Adap Rapida */
#define A_RA 0.1f
#define B_RA 0.2f
#define C_RA -65.0f
#define D_RA 2.0f
#define G_RA 1000.0f

/* Adap lenta */
#define A_SA 0.02f
#define B_SA 0.2f
#define C_SA -65.0f
#define D_SA 8.0f
#define G_SA 40.0f

//* Cuneate Neuron MM
#define A_CN 0.02f
#define B_CN 0.2f
#define C_CN -65.0f
#define D_CN 8.0f
#define G_CN 100000.0f

//* Cuneate Neuron FA
#define A_CNF 0.02f
#define B_CNF 0.2f
#define C_CNF -65.0f
#define D_CNF 8.0f
#define G_CNF 100000.0f

//* Cuneate Neuron SA
#define A_CNS 0.02f
#define B_CNS 0.2f
#define C_CNS -65.0f
#define D_CNS 8.0f
#define G_CNS 100000.0f

//* Cuneate Neuron - NEURONIO DO ARTIGO DA ANA
//#define A_CN 0.211f
//#define B_CN 0.228f
//#define C_CN -27.668f
//#define D_CN 31.761f
//#define G_CN 6.310e+09f

// Passo de integração dos Izhikevich, em MILISSEGUNDOS. Tem de ser o período
// real da ISR: TIM6 a 1 MHz com período 199 dispara a cada 200 us, e cada
// disparo roda um izhikevich_step por taxel. O valor antigo (0,10f) fazia o
// modelo andar a METADE do tempo real — todas as taxas de disparo saíam com
// fator 2. As constantes de ganho (G_RA, G_SA, G_CN*) foram ajustadas na
// bancada CONTRA o passo errado: precisam de nova calibração.
#define DT 0.20f

// Período de um frame 5x5 completo, em milissegundos: 5 linhas x 200 us.
// É o intervalo real entre duas visitas à MESMA linha, e é isso que separa
// duas amostras consecutivas de I_buffer.
#define FRAME_PERIOD_MS 1.0f

#define VTH 30.0f
#define V_MIN 0.0f
#define V_MAX 3.2f

// ── USB ───────────────────────────────────────────────────────────────
// USB_PACKET_SIZE é o wMaxPacketSize do endpoint bulk em Full Speed: 64 B.
// Ele NÃO é o teto de uma transferência — CDC_Transmit_FS aceita centenas de
// bytes e a própria pilha os fatia em pacotes de 64. Usar 64 como tamanho de
// transferência limitava a vazão a ~1 transferência por polling do host,
// muito abaixo dos ~143 KB/s que os frames ADC produzem a 1 kHz. [4]
#define USB_PACKET_SIZE     64
#define USB_TX_CHUNK        512     // bytes por transferência (múltiplo de 64)
#define USB_TX_BUFFER_SIZE  8192    // ring; >= 2x o chunk, potência de 2

// Linha de diagnóstico "STAT,drop=<n>,t=<us>". Período em ms; 0 desliga. [5]
#define USB_STAT_PERIOD_MS  1000

#define TS_64BIT 1

//#define SEND_INTERVAL_MS 100  // envio ADC a cada 10 ms

#define G_MAX 1.0f

#define TEMPLATE_SIZE 20



float g_template[TEMPLATE_SIZE];

//  ESTRUTURAS
typedef struct {
    float v_RA;
    float u_RA;

    float v_SA;
    float u_SA;
} Taxel;

typedef struct {
      float v_CN;
      float u_CN;
} CuneateNeuron;

typedef struct {
      float v_CNF;
      float u_CNF;
} CuneateNeuronFast;

typedef struct {
      float v_CNS;
      float u_CNS;
} CuneateNeuronSlow;


// HANDLES
ADC_HandleTypeDef hadc1;
DMA_HandleTypeDef hdma_adc1;
TIM_HandleTypeDef htim6;
TIM_HandleTypeDef htim2;
extern USBD_HandleTypeDef hUsbDeviceFS;

// Onde a pilha guarda o contexto da classe CDC. Nas versões mais novas da
// USB Device Library isto virou `pClassDataCmsit[0]`; se o projeto usar uma
// dessas, redefina este macro no build em vez de editar o código abaixo.
#ifndef USBD_CDC_CTX
#define USBD_CDC_CTX (hUsbDeviceFS.pClassData)
#endif

// VARIÁVEIS
Taxel taxels[NUM_TAXELS];
uint16_t adc_buffer[COLS];
uint8_t current_row = 0;

volatile uint8_t spike_flags_RA[NUM_TAXELS] = {0};
volatile uint8_t spike_flags_SA[NUM_TAXELS] = {0};

volatile uint16_t last_adc[NUM_TAXELS] = {0};

float I_buffer[NUM_TAXELS][DIFF_BUFFER] = {0}; // corrente excitatória
uint8_t I_index[NUM_TAXELS] = {0};

uint8_t usb_tx_buffer[USB_TX_BUFFER_SIZE];
volatile uint16_t usb_head = 0;
volatile uint16_t usb_tail = 0;
volatile uint32_t usb_dropped = 0;   // linhas descartadas por buffer cheio [5]

uint8_t template_idx_RA[NUM_TAXELS] = {0};
uint8_t template_idx_SA[NUM_TAXELS] = {0}; // em qual posição do template cada neurônio está

bool izhikevich_step(float *v, float *u, float I,
                     float a, float b, float c, float d);
CuneateNeuron CN;
CuneateNeuronFast CNF;
CuneateNeuronSlow CNS;

// PROTÓTIPOS
void SystemClock_Config(void);
void MX_GPIO_Init(void);
void MX_DMA_Init(void);
void MX_ADC1_Init(void);
void MX_TIM6_Init(void);
void MX_TIM2_Init(void);
void select_row(uint8_t row);
void update_taxels(Taxel *t, uint16_t *adc, uint8_t row_idx);
void process_spikes(void);
bool usb_buffer_write(const char *data, uint16_t len);
void usb_buffer_process(void);

void send_adc_frame(uint64_t tstamp);


// =====================================================
// SEÇÃO CRÍTICA
// =====================================================
//
// Salva e restaura o PRIMASK em vez de chamar __enable_irq() cego. Sem isto,
// uma seção crítica aninhada dentro de outra reabilitaria as interrupções ao
// sair da interna — e aqui há aninhamento real: process_spikes() fecha as
// interrupções para ler os flags e chama usb_buffer_write(), que as fecha de
// novo.

static inline uint32_t irq_save(void)
{
    uint32_t primask = __get_PRIMASK();
    __disable_irq();
    return primask;
}

static inline void irq_restore(uint32_t primask)
{
    if (primask == 0U)
    {
        __enable_irq();
    }
}


// =====================================================
// RELÓGIO DE 64 BITS (TIM2 a 1 MHz + extensão por software)
// =====================================================

#if TS_64BIT
static volatile uint32_t tim2_hi   = 0;
static volatile uint32_t tim2_last = 0;
#endif

/* Microssegundos desde o boot. Precisa ser chamado pelo menos uma vez por
 * volta do TIM2 (71,6 min) para não perder um incremento — é chamado a cada
 * frame (1 ms), então há margem de sobra. Seção crítica porque a ISR do ADC
 * e o laço principal chamam os dois. */
static uint64_t micros64(void)
{
#if TS_64BIT
    uint32_t primask = irq_save();

    uint32_t now = __HAL_TIM_GET_COUNTER(&htim2);

    if (now < tim2_last)
    {
        tim2_hi++;
    }

    tim2_last = now;

    uint64_t t = ((uint64_t)tim2_hi << 32) | (uint64_t)now;

    irq_restore(primask);

    return t;
#else
    return (uint64_t)__HAL_TIM_GET_COUNTER(&htim2);
#endif
}


// =====================================================
// FORMATADORES DECIMAIS
// =====================================================
//
// snprintf com 25 conversões %d rodava DENTRO da ISR do ADC, a 1 kHz. Estes
// formatadores fazem o mesmo trabalho em uma fração do tempo e produzem
// exatamente os mesmos caracteres, então o protocolo não muda. [9]

/* Escreve `v` em decimal em `out`. Devolve quantos caracteres escreveu. */
static uint16_t u32_to_dec(uint32_t v, char *out)
{
    char tmp[10];
    uint16_t n = 0;

    if (v == 0U)
    {
        out[0] = '0';
        return 1;
    }

    while (v > 0U)
    {
        tmp[n++] = (char)('0' + (v % 10U));
        v /= 10U;
    }

    for (uint16_t i = 0; i < n; i++)
    {
        out[i] = tmp[n - 1U - i];
    }

    return n;
}

static uint16_t u64_to_dec(uint64_t v, char *out)
{
    char tmp[20];
    uint16_t n = 0;

    if (v <= 0xFFFFFFFFULL)
    {
        // Caminho rápido: evita __aeabi_uldivmod enquanto o tempo couber em
        // 32 bits, que é o caso nas primeiras 71 min de qualquer ensaio.
        return u32_to_dec((uint32_t)v, out);
    }

    while (v > 0ULL)
    {
        tmp[n++] = (char)('0' + (uint32_t)(v % 10ULL));
        v /= 10ULL;
    }

    for (uint16_t i = 0; i < n; i++)
    {
        out[i] = tmp[n - 1U - i];
    }

    return n;
}

/* Fecha uma linha com "t=<micros>\r\n".
 *
 * `cap` é o tamanho do buffer e NÃO é decorativo: snprintf_len() devolve
 * cap-1 quando o snprintf trunca, e escrever o timestamp a partir dali
 * passaria 24 bytes do fim do array. Quando o timestamp não cabe no que
 * sobrou, o OFFSET é recuado para que ele caiba: a linha perde caracteres do
 * payload mas continua terminando em "t=<n>\r\n", que é o que o parser do PC
 * procura (`parts[-1]` em touch_source.py). Linha curta o host conta como
 * frame ruim; linha sem timestamp ele não conta de jeito nenhum. */
#define APPEND_TS_MAX 24U   /* "t=" + 20 digitos + CRLF */

static uint16_t append_ts(char *buf, uint16_t off, uint16_t cap, uint64_t t)
{
    char ts[APPEND_TS_MAX];
    uint16_t k = 0;

    ts[k++] = 't';
    ts[k++] = '=';
    k += u64_to_dec(t, ts + k);
    ts[k++] = '\r';
    ts[k++] = '\n';

    if (cap < k)
    {
        return off;                 // buffer menor que o timestamp: impossível
    }

    if ((uint32_t)off + k > cap)
    {
        off = (uint16_t)(cap - k);  // recua o payload para o timestamp caber
    }

    memcpy(buf + off, ts, k);

    return (uint16_t)(off + k);
}

/* snprintf devolve o tamanho que a string TERIA — pode passar do buffer.
 * Usar esse valor num memcpy/usb_buffer_write lê além do array. [10] */
static uint16_t snprintf_len(int n, size_t cap)
{
    if (n < 0)
    {
        return 0;
    }

    if ((size_t)n >= cap)
    {
        return (uint16_t)(cap - 1U);   // snprintf terminou em cap-1 + '\0'
    }

    return (uint16_t)n;
}


// VER VALOR POSIÇÃO DA PRIMEIRA
void init_template(void)
{
    g_template[0] = 0.0f;

    for(int i = 1; i < TEMPLATE_SIZE; i++)
    {
        g_template[i] =
            G_MAX * expf(-(float)(i-1) / 4.0f);

    }
}


// =====================================================
// USB BUFFER — ESCRITA
// =====================================================
//
// Duas correções num só lugar:
//
// [2] Seção crítica. `usb_buffer_write` tem DOIS produtores concorrentes: a
//     ISR do ADC (send_adc_frame e as linhas CN_*) e o laço principal
//     (process_spikes, FORCE, boot). O par
//         usb_tx_buffer[usb_head] = c;  usb_head = next;
//     não é atômico: uma ISR caindo entre as duas instruções escrevia no
//     mesmo índice e tinha o seu byte sobrescrito — caracteres de uma linha
//     apareciam no meio de outra.
//
// [3] All-or-nothing. A versão antiga copiava byte a byte e dava `break` ao
//     encher, cortando a linha no meio: o PC recebia um frame truncado e o
//     contava em `frames_bad`. Agora a mensagem só entra se couber inteira;
//     se não couber, é descartada por completo e contabilizada. Frame que
//     chega, chega íntegro.
//
// Devolve true se a mensagem entrou no buffer.

bool usb_buffer_write(const char *data, uint16_t len)
{
    if (len == 0U)
    {
        return true;
    }

    uint32_t primask = irq_save();

    uint16_t head = usb_head;
    uint16_t tail = usb_tail;

    // Espaço livre: uma posição fica sempre vaga para distinguir cheio de
    // vazio, daí o -1.
    uint16_t free_space =
        (uint16_t)((tail - head - 1U) % USB_TX_BUFFER_SIZE);

    if (len > free_space)
    {
        usb_dropped++;
        irq_restore(primask);
        return false;
    }

    for (uint16_t i = 0; i < len; i++)
    {
        usb_tx_buffer[head] = (uint8_t)data[i];
        head = (uint16_t)((head + 1U) % USB_TX_BUFFER_SIZE);
    }

    usb_head = head;

    irq_restore(primask);

    return true;
}


// =====================================================
// USB BUFFER — DRENAGEM
// =====================================================

/* True se a pilha CDC pode aceitar uma nova transferência AGORA. */
static bool usb_tx_ready(void)
{
    if (hUsbDeviceFS.dev_state != USBD_STATE_CONFIGURED)
    {
        return false;
    }

    USBD_CDC_HandleTypeDef *hcdc =
        (USBD_CDC_HandleTypeDef *)USBD_CDC_CTX;

    return (hcdc != NULL) && (hcdc->TxState == 0U);
}

//
// [1] A correção central. CDC_Transmit_FS apenas GUARDA o ponteiro
//     (USBD_CDC_SetTxBuffer) e devolve; no OTG_FS do F7 os bytes só são
//     empurrados para a FIFO depois, dentro da interrupção. O buffer tem de
//     ficar intacto até TxState voltar a zero.
//
//     A versão antiga enchia `packet` ANTES de saber se podia transmitir.
//     Como `usb_tail` já havia avançado na chamada bem-sucedida anterior, a
//     iteração seguinte do laço principal sobrescrevia `packet` com os bytes
//     SEGUINTES enquanto a transferência anterior ainda o estava lendo — o
//     host recebia as duas metades misturadas. Depois CDC_Transmit_FS
//     devolvia USBD_BUSY, `usb_tail` não avançava, e os mesmos bytes eram
//     reenviados: corrompidos E duplicados.
//
//     Agora o teste de TxState vem PRIMEIRO, antes de tocar em `packet`.
//
// [4] `packet` cresceu para USB_TX_CHUNK. A pilha fatia sozinha em pacotes
//     de 64 B, então uma transferência de 512 B vale 8 pacotes por polling
//     do host em vez de 1.

void usb_buffer_process(void)
{
    static uint8_t packet[USB_TX_CHUNK];

    // ANTES de encher o buffer. Ver [1].
    if (!usb_tx_ready())
    {
        return;
    }

    uint16_t len = 0;
    uint16_t temp_tail = usb_tail;
    uint16_t head = usb_head;      // snapshot: a ISR pode avançá-lo aqui

    while (temp_tail != head && len < USB_TX_CHUNK)
    {
        packet[len++] = usb_tx_buffer[temp_tail];
        temp_tail = (uint16_t)((temp_tail + 1U) % USB_TX_BUFFER_SIZE);
    }

    if (len == 0U)
    {
        return;
    }

    // Uma transferência de tamanho múltiplo do wMaxPacketSize precisa de um
    // pacote de comprimento zero para o host saber que acabou. Em vez de
    // emitir o ZLP, encurta em um byte: o pacote final fica curto e fecha a
    // transferência sozinho. O byte que sobrou vai na próxima rodada.
    if ((len % USB_PACKET_SIZE) == 0U)
    {
        len--;
        temp_tail =
            (uint16_t)((usb_tail + len) % USB_TX_BUFFER_SIZE);
    }

    if (CDC_Transmit_FS(packet, len) == USBD_OK)
    {
        usb_tail = temp_tail;   // confirma envio
    }
}

// SELECT ROW
static inline uint8_t row5(uint8_t v)
{
    return ((v << 1) | (v >> 4)) & 0x1F;
}

const uint8_t row_masks[ROWS] = {
    0b11110,
    0b11101,
    0b11011,
    0b10111,
    0b01111
};
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
int main(void)
{
    HAL_Init();

    SystemClock_Config();

    __HAL_RCC_GPIOA_CLK_ENABLE();

    MX_GPIO_Init();
    MX_DMA_Init();
    MX_ADC1_Init();
    MX_TIM6_Init();
    MX_TIM2_Init();
    MX_USB_DEVICE_Init();

    CN.v_CN = -30.0f;
    CN.u_CN = B_CN * CN.v_CN;

    CNF.v_CNF = -30.0f;
    CNF.u_CNF = B_CNF * CNF.v_CNF;

    CNS.v_CNS = -30.0f;
    CNS.u_CNS = B_CNS * CNS.v_CNS;

    init_template();

    // O TIM2 precisa estar rodando antes de qualquer micros64().
    HAL_TIM_Base_Start(&htim2);

    for (int i = 0; i < NUM_TAXELS; i++)
    {
        taxels[i].v_RA = -30.0f;
        taxels[i].u_RA =
            B_RA * taxels[i].v_RA;

        taxels[i].v_SA = -30.0f;
        taxels[i].u_SA =
            B_SA * taxels[i].v_SA;
    }

    select_row(0);

    HAL_TIM_Base_Start(&htim6);

    HAL_ADC_Start_DMA(
        &hadc1,
        (uint32_t*)adc_buffer,
        COLS
    );

    usb_buffer_write(
        "BOOT OK\r\n",
        9
    );

    static uint32_t last_stat_send = 0;

    while (1)
    {
        process_spikes();

        uint32_t now = HAL_GetTick();

        if ((now - last_stat_send) >= USB_STAT_PERIOD_MS)
        {
            last_stat_send = now;
            send_stat_line();
        }

        // Uma chamada por volta. A segunda que existia aqui era placebo: ela
        // caía no `if (!usb_tx_ready()) return`, porque TxState só volta a
        // zero quando a transferência anterior completa, microssegundos
        // depois, dentro da interrupção do OTG.
        usb_buffer_process();
    }
}
// GPIO
void MX_GPIO_Init(void)
{
    __HAL_RCC_GPIOA_CLK_ENABLE();
    // GPIOB estava sendo ligado LÁ EMBAIXO, depois do HAL_GPIO_Init de PB1.
    // Escrita em periférico com o clock fechado é descartada: PB1 (ADC9, a
    // quinta coluna) ficava no modo de reset — entrada digital, buffer
    // Schmitt ligado — em vez de analógica, em todos os frames desde sempre.
    __HAL_RCC_GPIOB_CLK_ENABLE();
    __HAL_RCC_GPIOC_CLK_ENABLE();
    __HAL_RCC_GPIOF_CLK_ENABLE();

    GPIO_InitTypeDef g = {0};

    /* LINHAS */
    g.Mode = GPIO_MODE_OUTPUT_PP;
    g.Pull = GPIO_NOPULL;
    g.Speed = GPIO_SPEED_FREQ_LOW;

    g.Pin = GPIO_PIN_0 | GPIO_PIN_3;
    HAL_GPIO_Init(GPIOC, &g);

    g.Pin = GPIO_PIN_3 | GPIO_PIN_5 | GPIO_PIN_10;
    HAL_GPIO_Init(GPIOF, &g);

    /* PINOS ADC */
    g.Mode = GPIO_MODE_ANALOG;
    g.Pull = GPIO_NOPULL;
    g.Pin = GPIO_PIN_0 | GPIO_PIN_3 | GPIO_PIN_4 | GPIO_PIN_6; // ADC0, ADC3, ADC4, ADC6
    HAL_GPIO_Init(GPIOA, &g);

    g.Pin = GPIO_PIN_1; // ADC9
    HAL_GPIO_Init(GPIOB, &g);

    ///////////////////////////////////////////////////////////

    g.Mode = GPIO_MODE_OUTPUT_PP;
    g.Pull = GPIO_NOPULL;
    g.Speed = GPIO_SPEED_FREQ_VERY_HIGH;

    g.Pin = DEBUG_ADC_PIN | DEBUG_IZH_PIN;
    HAL_GPIO_Init(GPIOB, &g);
}

// DMA
void MX_DMA_Init(void)
{
    __HAL_RCC_DMA2_CLK_ENABLE();

    hdma_adc1.Instance = DMA2_Stream0;
    hdma_adc1.Init.Channel = DMA_CHANNEL_0;
    hdma_adc1.Init.Direction = DMA_PERIPH_TO_MEMORY;
    hdma_adc1.Init.PeriphInc = DMA_PINC_DISABLE;
    hdma_adc1.Init.MemInc = DMA_MINC_ENABLE;
    hdma_adc1.Init.PeriphDataAlignment = DMA_PDATAALIGN_HALFWORD;
    hdma_adc1.Init.MemDataAlignment = DMA_MDATAALIGN_HALFWORD;
    hdma_adc1.Init.Mode = DMA_CIRCULAR;
    hdma_adc1.Init.Priority = DMA_PRIORITY_HIGH;
    hdma_adc1.Init.FIFOMode = DMA_FIFOMODE_DISABLE;

    HAL_DMA_Init(&hdma_adc1);
    __HAL_LINKDMA(&hadc1, DMA_Handle, hdma_adc1);

    // Prioridade 5, não 0. Na 0 esta ISR era a mais alta do sistema, acima
    // do OTG_FS: a cada 1 ms ela roda o passo de 25 neurônios e monta os 153
    // bytes do frame ADC, e enquanto isso o USB não era atendido. Agora o
    // OTG_FS (que fica na 0 por padrão do CubeMX) a preempta; a ISR do ADC
    // continua com 200 us de folga para terminar.
    HAL_NVIC_SetPriority(DMA2_Stream0_IRQn, 5, 0);
    HAL_NVIC_EnableIRQ(DMA2_Stream0_IRQn);
}

void DMA2_Stream0_IRQHandler(void)
{
    HAL_DMA_IRQHandler(&hdma_adc1);
}

// ADC
void MX_ADC1_Init(void)
{
    __HAL_RCC_ADC1_CLK_ENABLE();

    ADC_ChannelConfTypeDef c = {0};

    hadc1.Instance = ADC1;
    hadc1.Init.Resolution = ADC_RESOLUTION_12B;
    hadc1.Init.ScanConvMode = ENABLE;
    hadc1.Init.ContinuousConvMode = DISABLE;
    hadc1.Init.NbrOfConversion = COLS;
    hadc1.Init.ExternalTrigConv = ADC_EXTERNALTRIGCONV_T6_TRGO;
    hadc1.Init.ExternalTrigConvEdge = ADC_EXTERNALTRIGCONVEDGE_RISING;
    hadc1.Init.DMAContinuousRequests = ENABLE;
    HAL_ADC_Init(&hadc1);

    uint32_t ch[COLS] = {
        ADC_CHANNEL_0,
        ADC_CHANNEL_3,
        ADC_CHANNEL_4,
        ADC_CHANNEL_6,
        ADC_CHANNEL_9,
    };

    for (int i = 0; i < COLS; i++)
    {
        c.Channel = ch[i];
        c.Rank = i + 1;
        c.SamplingTime = ADC_SAMPLETIME_15CYCLES;
        HAL_ADC_ConfigChannel(&hadc1, &c);
    }
}

// TIM6
void MX_TIM6_Init(void)
{
    __HAL_RCC_TIM6_CLK_ENABLE();

    htim6.Instance = TIM6;
    htim6.Init.Prescaler = 83;
    htim6.Init.Period = 199; //microsegundos -- cada taxel atualizado em 1 ms

    HAL_TIM_Base_Init(&htim6);

    TIM_MasterConfigTypeDef s = {0};
    s.MasterOutputTrigger = TIM_TRGO_UPDATE;
    s.MasterSlaveMode = TIM_MASTERSLAVEMODE_DISABLE;
    HAL_TIMEx_MasterConfigSynchronization(&htim6, &s);
}

// ========================== TIM2
void MX_TIM2_Init(void)
{
    __HAL_RCC_TIM2_CLK_ENABLE();

    htim2.Instance = TIM2;
    htim2.Init.Prescaler = 83;
    htim2.Init.Period = 0xFFFFFFFF;
    HAL_TIM_Base_Init(&htim2);
}

// ========================== CLOCK ==========================
void SystemClock_Config(void)
{
    RCC_OscInitTypeDef o = {0};
    RCC_ClkInitTypeDef c = {0};

    o.OscillatorType = RCC_OSCILLATORTYPE_HSE;
    o.HSEState = RCC_HSE_BYPASS;
    o.PLL.PLLState = RCC_PLL_ON;
    o.PLL.PLLSource = RCC_PLLSOURCE_HSE;
    o.PLL.PLLM = 8;
    o.PLL.PLLN = 336;
    o.PLL.PLLP = RCC_PLLP_DIV2;
    o.PLL.PLLQ = 7;
    HAL_RCC_OscConfig(&o);

    c.ClockType = RCC_CLOCKTYPE_SYSCLK | RCC_CLOCKTYPE_HCLK |
                  RCC_CLOCKTYPE_PCLK1 | RCC_CLOCKTYPE_PCLK2;
    c.SYSCLKSource = RCC_SYSCLKSOURCE_PLLCLK;
    c.AHBCLKDivider = RCC_SYSCLK_DIV1;
    c.APB1CLKDivider = RCC_HCLK_DIV4;
    c.APB2CLKDivider = RCC_HCLK_DIV2;
    HAL_RCC_ClockConfig(&c, FLASH_LATENCY_5);
}

void Error_Handler(void)
{
    __disable_irq();
    while (1);
}

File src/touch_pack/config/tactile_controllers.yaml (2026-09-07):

# ============================================================================
#  tactile_controllers.yaml — Configuração ros2_control para a célula de
#  palpação tátil (CR10 + TCP de palpação com sensor tátil 5×5).
#
#  Controladores disponíveis:
#    cr10_group_controller   JointTrajectoryController (ativo em runtime)
#    admittance_controller   AdmittanceController (futuro — palpação com
#                            FT sensor físico no flange ou no probe)
#
#  Observação: ft_sensor_broadcaster e hand_position_controller foram
#  removidos — pertencem ao modo "hand" (cr10_covvi_controllers.yaml).
#  O admittance_controller não é spawned pelo launch atual; está aqui
#  como referência para ativação futura via controller_manager CLI.
# ============================================================================

controller_manager:
  ros__parameters:
    update_rate: 250   # Hz

    joint_state_broadcaster:
      type: joint_state_broadcaster/JointStateBroadcaster

    cr10_group_controller:
      type: joint_trajectory_controller/JointTrajectoryController

    admittance_controller:
      type: admittance_controller/AdmittanceController


# ────────────────────────────────────────────────────────────────────────────
#  joint_trajectory_controller (movimentos rígidos — home, jog, recuo)
# ────────────────────────────────────────────────────────────────────────────
cr10_group_controller:
  ros__parameters:
    joints:
      - joint1
      - joint2
      - joint3
      - joint4
      - joint5
      - joint6
    command_interfaces:  [position]
    state_interfaces:    [position, velocity]
    state_publish_rate:  100.0
    action_monitor_rate: 50.0
    allow_partial_joints_goal: false
    constraints:
      stopped_velocity_tolerance: 0.05
      goal_time: 1.5


# ────────────────────────────────────────────────────────────────────────────
#  admittance_controller — controle de força com FT físico (uso futuro)
#
#  Modelo: M·ẍ + D·ẋ + K·x = F_ext
#    M = matriz de inércia aparente (massa virtual)
#    D = matriz de amortecimento viscoso
#    K = rigidez (mola virtual) que puxa o TCP de volta para o setpoint
#    F_ext = wrench do FT físico (hardware interface do controlador CR10
#            ou sensor externo via ros2_control ForceTorqueSensor)
#
#  Eixo de aproximação (palpação vertical/horizontal):  Z ou X do tcp_link
#    → selected_axes[2]=true habilita admitância em Z.
#    → mass[2]=2.0 → sistema reativo à força externa.
#    → stiffness[2]=40 N/m (mola fraca) → força externa governa profundidade.
#    → damping_ratio[2]=1.6 (super-amortecido) → sem oscilação no contato.
#
#  Como ajustar:
#    - Vibração no contato     → aumentar damping_ratio[2] para 2.0+
#    - Força não atinge alvo   → diminuir stiffness[2] (e.g. 20)
#    - Movimento muito mole    → aumentar stiffness em X/Y para 800+
# ────────────────────────────────────────────────────────────────────────────
admittance_controller:
  ros__parameters:
    joints:
      - joint1
      - joint2
      - joint3
      - joint4
      - joint5
      - joint6

    command_interfaces:  [position]
    state_interfaces:    [position, velocity]
    chainable_command_interfaces:
      - position

    kinematics:
      plugin_name:    kinematics_interface_kdl/KinematicsInterfaceKDL
      plugin_package: kinematics_interface_kdl
      base:           base_link
      tip:            tcp_link
      alpha:          0.0005

    ft_sensor:
      name: ft_sensor
      frame:
        id: tcp_link       # frame do probe (existe tanto no touch_tool quanto na hand)
        external: false
      filter_coefficient: 0.05

    control:
      frame:
        id: tcp_link

    fixed_world_frame:
      frame:
        id: base_link

    gravity_compensation:
      frame:
        id: tcp_link
      CoG:
        # Centroide do conjunto do TCP (flange fixo + célula FA7155 de 6 eixos
        # + acoplador hot-swap + ponteira F), calculado da geometria real por
        # scripts/gen_tcp_meshes_from_step.py na pilha ft6:
        # 0.3837 kg com CoM em Z = +19.5 mm do flange → −48.2 mm no frame do
        # tcp_link (+67.7 mm). A célula responde por 78 % da massa.
        # A pilha da viga S que esteve aqui até 07/09/2026 pesava 0.6034 kg
        # com CoM a −103.5 mm: 57 % mais massa e o dobro do braço.
        pos:   [0.0, 0.0, -0.0482]
        force: 3.76   # m * g = 0.3837 * 9.80665

    admittance:
      # Eixos cartesianos do `control.frame` (tcp_link):
      #   [X,  Y,  Z,  rx, ry, rz]
      #   Z = eixo de aproximação vertical (palpação de superfície horizontal)
      selected_axes:  [false, false, true,  false, false, false]

      mass:           [5.0,   5.0,   2.0,   0.10,  0.10,  0.10]
      damping_ratio:  [1.0,   1.0,   1.6,   1.0,   1.0,   1.0]
      stiffness:      [500.0, 500.0, 40.0,  8.0,   8.0,   8.0]

      enable_parameter_update_without_reactivation: true

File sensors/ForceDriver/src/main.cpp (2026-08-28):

#include <Arduino.h>
#include "HX711.h"

// ─────────────────────────────────────────────────────────────────────
// Seeed XIAO ESP32C6 + HX711 — driver da célula axial de 100 kg.
// Firmware SERIAL-ONLY: a única saída é a linha ASCII pela USB.
//
// REESCRITO EM 28/08/2026, e o critério da reescrita foi ESTABILIDADE e não
// taxa. A versão anterior perseguia as 82 Hz do conversor sincronizando pela
// borda de descida do DOUT, e a bancada respondeu com o oposto do prometido:
// medido no mesmo binário, a entrega caiu de 58,8 Hz para 11,8 Hz ao longo de
// dez minutos, com os travamentos do HX711 subindo de 112 para 160 e a placa
// entrando em ciclo de reboot. Ler mais rápido não é ler melhor quando o
// caminho até o dado não sustenta a taxa.
//
// O que ficou de pé destas medidas, e vale registrar porque custou bancada:
//
//   pull-up no DOUT depois do begin()   OBRIGATÓRIO. A bogde/HX711 o desliga
//                                       de propósito em Espressif (HX711.cpp:65,
//                                       nota do ESP8266). Sem ele: σ de 6527
//                                       counts (1,5 N) contra ~200 com ele.
//   guarda de tempo entre leituras      OBRIGATÓRIA. Sem ela o loop relojoa o
//                                       chip antes da conversão terminar e os
//                                       counts viram lixo (σ 21127).
//   DOUT que não sobe após o 25º pulso  é chip TRAVADO, não USB engasgando.
//                                       Só o power-cycle o recupera.
//
// A guarda de 40 ms (24 Hz) é a que sustentou uso prolongado. 20 ms passou em
// 60 s e dessincronizou depois de alguns minutos — o oscilador RC interno do
// HX711 deriva com temperatura, e uma guarda perto do período de conversão
// deixa de ter margem quando o chip esquenta. O que compra robustez é a
// MARGEM sobre o período medido (12135–12154 µs), não a taxa nominal.
// ─────────────────────────────────────────────────────────────────────

#define HX_DOUT_PIN  D1
#define HX_SCK_PIN   D3
#define HX_GAIN      128        // canal A

// Piso de tempo entre leituras. NÃO reduzir sem validar por VÁRIOS MINUTOS:
// 60 s não provam estabilidade, foi essa a lição do 20 ms.
#define HX_PERIOD_US         40000L
// Prazo para o dado ficar pronto depois da guarda. Generoso de propósito:
// cobre até o modo lento do pino RATE (GND = 10 Hz, 100 ms por conversão),
// então trocar o jumper não vira falha.
#define HX_READY_TIMEOUT_MS  200
// Fundo de escala do canal A com ganho 128: ±0,5·AVDD/128 = ±2²⁴/256 counts.
// A célula em repouso lê ~-29000 e a 100 kg nominais ~-45000, então nada
// fisicamente medível passa daqui — o que vier além é bit deslocado, não
// força. Espelha LC_FS_COUNTS do constants.py.
#define HX_FS_COUNTS         65536L

// ── Detecção de célula DESCONECTADA ──────────────────────────────────
// Três defeitos que de fora parecem o mesmo silêncio, e que o firmware
// precisa saber separar porque a ação é diferente em cada um:
//
//   DOUT preso em HIGH      não há HX711 respondendo — placa sem alimentação,
//                           DT solto, ou o chip morreu. Power-cycle não
//                           resolve; é fiação.
//   counts fora de escala   há chip, mas a leitura não é força: ponte de 4
//                           fios solta, ou o chip dessincronizado.
//   counts CONGELADOS       o valor não muda em N leituras seguidas. O HX711
//                           travado devolve o mesmo número indefinidamente, e
//                           esse é o modo que atravessava todos os filtros:
//                           um valor plausível, constante, que o host tratava
//                           como uma célula muito quieta.
#define HX_STUCK_REPEATS     40     // leituras idênticas = congelado
#define HX_BAD_BEFORE_RESET  10     // leituras ruins antes do power-cycle
#define HX_RESET_COOLDOWN_MS 500    // intervalo mínimo entre power-cycles

// Auto-zero de boot: trava o repouso como offset ao ligar (a célula é
// bidirecional). REQUISITO: ligar/re-zerar com a célula EM REPOUSO. O comando
// 'Z' pela USB refaz o zero sob demanda. Nada é transmitido sem zero travado.
#define ZERO_SAMPLES         40
#define ZERO_STABLE_V        0.0002f   // faixa máx durante a coleta (~0,23 N)
#define ZERO_RELAX_MS        3000
// Teto do afrouxamento. 0,002 V ÷ 8,7e-4 V/N = 2,3 N de faixa aceita: um zero
// travado no pior caso carrega ±1,15 N de dispersão. Afrouxar é preferível a
// ficar mudo, mas não é de graça — a faixa ALCANÇADA vai no heartbeat
// (zero_mv=) e o force_receiver avisa quando ela é grande.
#define ZERO_STABLE_MAX_V    0.002f

// Sem leitura válida por este tempo o firmware se considera parado.
#define STALL_MS             5000UL
// Validade do aviso de ENSAIO EM CURSO ('B'). O host reenvia a cada segundo;
// se ele morrer o aviso expira e o reinício volta a ser permitido, que é o
// fail-safe certo — host morto é ensaio nenhum.
#define RUN_FLAG_TTL_MS      3000UL

// v_sensor = counts·AVDD/2²⁴ (tensão da ponte, já ×PGA). MANTER SINCRONIZADO
// com LC_FW_VOLTAGE_SCALE do constants.py. O quadro leva TAMBÉM os counts
// crus (5º campo): o inteiro é a medida, e o volt é uma interpretação dele
// com uma constante que os dois lados do cabo precisam jurar manter igual.
// HX_VREF fica como constante NOMEADA de propósito: o
// test_the_voltage_scale_matches_the_firmware extrai os dois números daqui e
// os confere contra LC_FW_VOLTAGE_SCALE. Inline o 3.3 e o contrato deixa de
// ser verificável — os dois lados do cabo voltam a se acertar por promessa.
static const float HX_VREF     = 3.3f;
static const float COUNTS_TO_V = HX_VREF / 16777216.0f;

static HX711 hx;

// ── Estado ───────────────────────────────────────────────────────────
static uint32_t tx_seq      = 0;
static float    g_v_offset  = 0.0f;
static bool     g_zeroed    = false;
static float    g_zero_acc  = 0.0f, g_zero_min = 0.0f, g_zero_max = 0.0f;
static int      g_zero_cnt  = 0;
static float    g_zero_tol  = ZERO_STABLE_V;
static float    g_zero_span = 0.0f;      // faixa do último zero TRAVADO
static uint32_t g_zero_t0   = 0;
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

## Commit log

2026-08-26 Primeiro commit
    [CelulaDeCarga_5kg_Montagem.step, CelulaDeCarga_5kg_Montagem.stl, FA7155 固定端法兰（需另购）.STEP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]
2026-08-26 Aponta eci_ros para 100f8e0: package.xml do covvi_hand_driver declara rclpy e covvi_interfaces
2026-08-26 README: nota sobre package.xml incompletos para rosdep install
2026-08-26 atualizações para adequação da celula usada
2026-08-27 att celula de carga
2026-08-27 celula de carga antiga
    [tactile_controllers.yaml, touch_tool_tcp.urdf]
2026-08-28 modulação de força
2026-09-01 controle pronto para experimentos
    [touch_tool_tcp.urdf]
2026-09-07 new load cell ft6
    [tactile_controllers.yaml, touch_tool_tcp.urdf]
2026-09-07 moldes novos
    [molde_D.step, montagem_molde_D.step, tampa_D.step]
2026-09-09 dados: campanha de indentação glass + silicon (09/09/2026)
    [adc.csv, cuneiformes.csv, samples.csv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]
2026-09-09 mudanças de segurança
2026-10-08 inicio IMU
2026-10-08 continuacao IMU
2026-10-12 IMU tracking
2026-10-13 coletas IMUS
2026-10-27 coletas de da dados
